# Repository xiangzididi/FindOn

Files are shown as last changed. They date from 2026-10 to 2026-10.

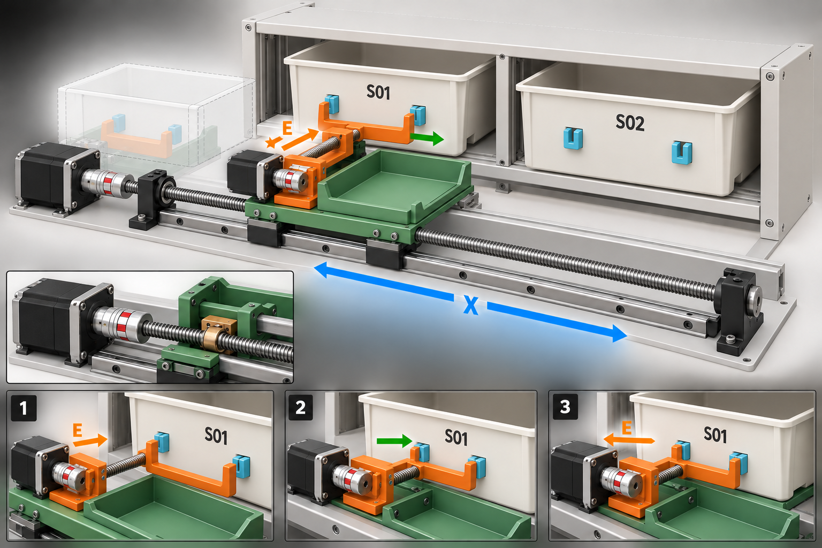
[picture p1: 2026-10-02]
docs/product-mechanism-concept-v1.png

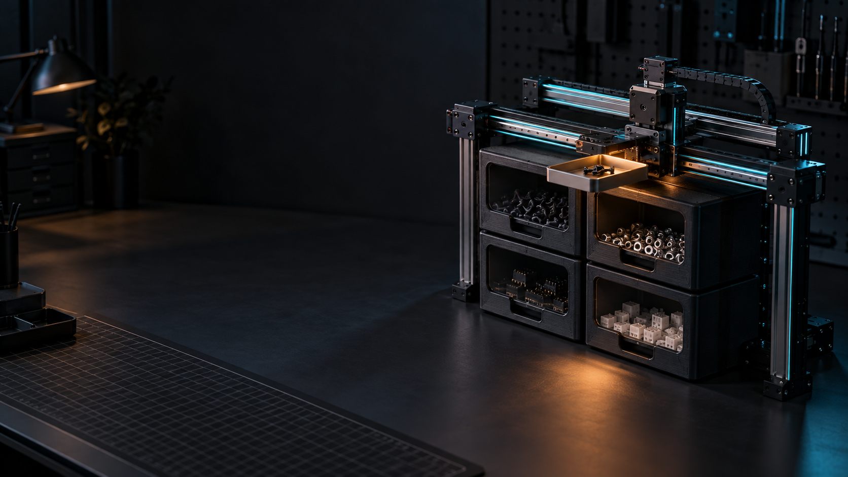
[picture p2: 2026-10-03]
public/assets/images/partgo-workbench-bg.jpg

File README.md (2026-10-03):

# PartGo · 桌面智能零件调度系统

PartGo 是桌面二维抽屉阵列式零件柜的 48 小时演示项目。电脑上的本地服务管理零件名称、盒位和任务历史，通过 USB 串口向 ESP32-S3 发送 `REFERENCE / FETCH / RETURN / STOP / RECOVER` 业务命令；ESP32-S3 控制 PD42S1 X 轴和 A4988 E 轴完成选格与抽盒。

当前演示配置启用同一层的 `S01/B01`、`S02/B02`，界面同时显示第二层 `S03/S04` 扩展位。加入 Y 轴并标定之前，第二层明确显示为不可用。

## 当前完成状态

- 新 PartGo 响应式前端已接入真实后端状态，支持搜索、浏览器语音、BOM 导入、格口编辑和批量顺序取料。
- Node.js 本地服务只监听 `127.0.0.1`，用 SQLite 保存盒位、任务、阶段事件和人工确认。
- USB 串口桥支持自动重连、控制器握手、JSONL 分片、任务超时和立即停止。
- ESP32-S3 最终固件已编译通过；上电不运动，未标定时报告 `CONFIG_LOCKED`。
- 取件送达和回件结束都要求操作员确认盒子实际位置。当前没有限位、编码器或盒体传感器，界面只显示真实存在的“开环脉冲计数”。
- 1×2 当前硬件与 2×2/Y 轴扩展共用一套格口协议和前端布局。

## 安全模拟演示

要求 Node.js 24 或更新版本。前端无需构建，也无需安装 npm 包。

```powershell
cd D:\Hackathon1st\Hackathon1st
node server.js
```

打开 <http://127.0.0.1:3210>：

1. 点击“确认机械原点”，勾选确认项。模拟模式只登记坐标，不驱动硬件。
2. 选择 `S01` 或 `S02`，确认运动区域清空后开始取件。
3. 等待页面进入“已到取物口”，取用零件并勾选取物口已清空。
4. 点击归还；模拟动作结束后目视确认提示，再点击“确认料盒已完整归位”。
5. 可导入 `.xlsx / .xls / .csv / .txt` 清单并按顺序处理已匹配的格口。

数据库保存在 `data/cabinet.sqlite`。不应同时启动多个服务进程打开同一数据库。

## USB 串口模式

Windows 下可直接双击项目根目录的 `启动管理系统.bat`。它只会关闭由本项目启动、身份核验一致且已确认空闲的旧进程；存在运动、待确认盒子、待恢复状态或无法读取旧服务状态时，会拒绝强制切换。如果 `COM9` 被其他程序占用，也会明确报错而不会结束未知进程。双击 `启动标定台.bat` 可切换到标定台；两个启动器默认使用 `COM9`，也可在命令行把其他串口作为第一个参数传入。

Python 只用于打开串口和解析 Excel：

```powershell
python -m pip install -r requirements.txt
.\start-hardware.ps1 -Port COM9
```

也可直接设置环境变量：

```powershell
$env:PARTGO_DEVICE_MODE = "hardware"
$env:PARTGO_SERIAL_PORT = "COM9"
$env:PARTGO_SERIAL_BAUD = "115200"
node server.js
```

服务会自动重连，但只有同时通过 `partgo-serial-v1` 握手、配置版本和标定指纹校验后才允许运动。旧轴测试固件、旧业务固件或参数不一致的固件只显示诊断状态，不会被当成可用控制器。任务进行时，主机每 500 ms 续租；控制器连续 2 s 收不到同一主机会话的心跳就停止输出并将任务判为失败。

## 固件

- `firmware/esp32s3_axis_test`：人工标定专用。保留受限点动/脉冲测试，不执行自动任务。
- `firmware/esp32s3_controller`：最终 USB 业务控制固件，同时兼容标定台的一次性受限人工移动。

编译最终固件：

```powershell
$pio = "$env:USERPROFILE\.platformio\penv\Scripts\platformio.exe"
& $pio run -d .\firmware\esp32s3_controller
```

最终固件的机械参数已经完整：X 比例为 `20000 pulse/mm`，E 根据带载实测“100 脉冲 = 19.6 mm”采用 `250/49 pulse/mm`（约 `5.1020 pulse/mm`）；48 mm 对接行程发送 245 个全步脉冲，相对 51 mm 实测可用行程保留约 3 mm 机械余量。`S01/S02` 的格口对位坐标分别为 `29.8 mm / 105 mm`，挂取动作再向右横移 `5.2 mm`。编译后的控制器不再处于 `CONFIG_LOCKED`，但每次上电仍必须把 X 放在最左侧取物处、E 完全回缩并由操作员确认原点后，才接受取回任务。完整协议见 [USB 串口协议 v1](docs/serial-protocol-v1.md)。

## 本地标定台

需要重新标定时，先烧录 `esp32s3_axis_test` 测试固件，把 X/E 滑块放在行程中间并打开电机电源。标定工具默认连接 `COM9`：

```powershell
.\start-calibration.ps1 -Port COM9
```

打开 <http://127.0.0.1:3212>。工具每次只发送一次 `ARM` 和一次有限运动，不提供连续转动；X 单次限制为 1–20 mm，E 在当前全步模式下单次限制为 1–100 脉冲。运动完成后填入卡尺实测距离，工具按当前实测比例换算标定基准。随后录入 E 对接行程、S01/S02 相对取物区的 X 坐标和方向，点击“写入最终固件配置”。

标定结果保存到 `config/motion-calibration.json`，同时生成 `firmware/esp32s3_controller/src/machine_calibration.h`。两者包含同一份安全参数指纹，上位机启动和控制器握手都会核对。缺少任何必需参数时不会写入，最终固件继续保持 `CONFIG_LOCKED`。无硬件时可验证界面：

```powershell
.\start-calibration.ps1 -Simulate
```

模拟模式会生成虚拟回执，不能作为实机标定结果，也不能写入或覆盖生产标定文件。

## 验证

```powershell
node --test
node --check server.js
node --check lib/cabinet.js
node --check lib/device.js
node --check lib/serial-transport.js
node --check public/app.js
node --check calibration/app.js
& "$env:USERPROFILE\.platformio\penv\Scripts\python.exe" -m unittest discover -s test -p "test_*.py"
```

固件验证：

```powershell
& "$env:USERPROFILE\.platformio\penv\Scripts\platformio.exe" run -d .\firmware\esp32s3_controller
```

自动化测试覆盖完整取回闭环、任务互斥与幂等、阶段顺序、人工盒位确认、故障/停止/超时、重启恢复、USB 握手、固件版本与标定指纹、任务心跳、受控恢复、串口分片与断线、HTTP 接口和数据库持久化。

## 目录

```text
server.js                         本机 HTTP 服务、静态资源与 BOM 接口
lib/cabinet.js                    SQLite、库存和任务状态机
lib/device.js                     模拟设备、JSONL 与 USB 设备适配器
lib/serial-transport.js           自动重连的 Python 串口桥进程
scripts/serial_bridge.py          pyserial 原始字节桥
scripts/parse_bom.py              本地 BOM 文件解析
scripts/calibration_server.py     有限运动、测量与固件参数生成
calibration/                      本地标定台网页
start-calibration.ps1             标定台启动入口
public/                           PartGo 前端，无构建步骤
firmware/esp32s3_axis_test/       标定测试固件
firmware/esp32s3_controller/      最终控制固件
docs/serial-protocol-v1.md        主机与 ESP32-S3 指令集合
config/cabinet.json               1×2 启用格与 2×2 扩展配置
config/motion-calibration.json    机械标定数据
test/cabinet.test.js              状态机、串口与 HTTP 测试
```

## 本机 API

`GET /api/state` 返回界面状态和临时请求令牌。所有写请求携带 `X-Cabinet-Token`；服务不对局域网或公网开放。

| 方法 | 路径 | 作用 |
| --- | --- | --- |
| `GET` | `/api/state` | 布局、设备、盒位和任务状态 |
| `PATCH` | `/api/boxes/{id}` | 更新零件名称和别名 |
| `POST` | `/api/tasks` | 提交取件或回件任务 |
| `POST` | `/api/tasks/{id}/confirm` | 人工确认盒子实际位置 |
| `POST` | `/api/device/reference` | 人工登记 X/E 原点 |
| `POST` | `/api/device/stop` | 软件停止并进入待恢复状态 |
| `POST` | `/api/device/recover` | 真实设备人工检查后恢复盒位记录 |
| `POST` | `/api/simulation/reset` | 仅模拟模式恢复初始状态 |
| `POST` | `/api/bom/import` | 本地解析 BOM 文件，最大 5 MB |

软件停止不能代替实体断电急停。当前设备没有实体急停和限位开关，调试时必须有人全程看护，并确保能立即切断 12 V 电机电源。ESP32 由 USB 独立供电，无法感知 12 V 是否断过；所以断线、停止、控制器复位、12 V 断电/重上电或动作不完整后，都必须先检查机械位置，再执行人工恢复和原点确认。

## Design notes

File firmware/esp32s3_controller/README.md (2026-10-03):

# ESP32-S3 最终控制固件

这是 PartGo 本地后端配套的 USB JSONL 控制器。它与 `esp32s3_axis_test` 分开保存：测试固件用于标定，控制固件只执行有限的业务任务。

当前机械配置已经完整：

- X 轴已测得 `20000 pulse/mm`；
- A4988 的 MS1/MS2/MS3 均接地，E 轴处于全步模式；带载实测100脉冲移动19.6mm，比例为 `250/49 pulse/mm`（约 `5.1020 pulse/mm`）；
- E 轴真实可用行程为 `51 mm`，对接命令取 `48 mm`，保留约 `3 mm` 机械余量；
- `S01`、`S02` 的格口对位坐标分别为 `29.8 mm`、`105 mm`，挂取时再向右横移 `5.2 mm`；
- 没有限位开关和 Y 轴。

本地标定台已经生成 `src/machine_calibration.h`。取件顺序为“到格口、E 伸出、X 右移挂钩、E 回缩、回取物区”，回件执行逆序释放动作。上电状态为 `UNREFERENCED`，不会自动运动；把 X 放在最左侧取物处、E 完全回缩并人工确认原点后才接受 `FETCH/RETURN`。

E轴由独立的 `e_axis.cpp/.h` 控制器管理，不再复用X轴运动结构。控制器单独维护A4988的STEP/DIR/EN时序、按比例换算得到的245脉冲对接行程、方向、超时和位置可信状态；伸出后保持使能，完成挂钩或脱钩横移后再执行负方向回缩并释放使能。

业务协议当前为配置版本 `6`。主机和控制器必须持有同一标定指纹；任务期间还必须维持同一主机会话的心跳租约，连续2秒失联会关断运动输出并报错。`RECOVER` 只清除逻辑状态，不产生电机脉冲，且要求操作员确认所有盒子都在柜内、运动区域已清空。当前没有实体急停，实机运行时必须有人能直接切断12V电机电源。

最终固件同时兼容本地标定台的受限人工控制：先发送 `ARM X/E CLEAR`，再执行一次 `TRAVEL X ±1–20 mm` 或 `PULSE E ±1–100`。授权 10 秒失效且只能使用一次；人工移动会清除原点状态，之后必须重新执行人工 `REFERENCE`。存在正在取还件的任务或有盒子停在取物区时，人工移动会被拒绝。

```powershell
$pio = "$env:USERPROFILE\.platformio\penv\Scripts\platformio.exe"
& $pio run -d .\firmware\esp32s3_controller
& $pio run -d .\firmware\esp32s3_controller -t upload --upload-port COM9
```

完整消息格式见 `docs/serial-protocol-v1.md`。

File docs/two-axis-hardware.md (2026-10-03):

# 单层两格：PD42S1 + A4988

接线图 R2：[PNG 预览](cabinet-wiring.png) / [SVG 矢量原图](cabinet-wiring.svg)。绘图源文件为 `scripts/draw-wiring.js`。图中 GPIO 是待实机复核的候选分配，12 V 是供电规划值。

## 已确认的硬件

- 主控：ESP32-S3-N16R8。
- X：PD42S1 PLC-TTL STEP/DIR，1.8° 电机、16 细分、1:50 减速箱、2 mm 导程丝杆/导轨，名义总行程 250 mm。
- E：三星光驱拆机微型步进电机、红色 A4988 StepStick 兼容板。2026-10-03 为提高带载启动能力，MS1/MS2/MS3 已由 3.3 V（1/16 细分）改接 GND（全步）；直接驱动标记为 T4 的丝杆，名义总行程约 50 mm，电机电源为 12 V。
- 当前 X/E 均没有微动开关，也没有盒子到位传感器。
- 导轨最左侧空位为固定取物区，一层两格为 S01、S02。

待标定参数记录在 `config/hardware.pending.json`。该文件不被业务服务或自动运动固件加载，`motion_enabled` 保持为 `false`。

## 机构与动作

X 滑块承载取货平台、E 丝杆模组和托盘；E 滑块连接双钩横梁。丝杆施力、托盘承重，移动线缆须覆盖全部 X 行程。柜格底面与托盘承接面应平齐，交界处不能卡住盒底。

取件顺序：

1. 人工确认 E 在完全回缩安全位置。
2. X 到目标格未嵌合坐标。
3. E 伸入到挂钩深度。
4. X 向右短移，使平台双钩与盒子双钩嵌合。
5. E 回缩，把盒子拉到托盘。
6. 人工确认盒子完全离柜且承托稳定。
7. X 左移到固定取物区。

回件按反序执行：X 到原柜格已嵌合坐标 → E 推回盒子 → X 向左短移脱钩 → E 空载回缩 → X 返回取物区。

每格需要未嵌合和已嵌合两个 X 坐标：`S01_ALIGN/S01_ENGAGED`、`S02_ALIGN/S02_ENGAGED`。若钩形相同，可使用公共 `HOOK_SHIFT = ENGAGED - ALIGN`。E 未回缩时，X 只允许执行已标定的短距离嵌合/脱钩，禁止跨格或去取物区。

结构概念图：[product-mechanism-concept-v1.png](product-mechanism-concept-v1.png)。它用于说明动作关系，不是加工尺寸图。

## 接线规划

N16R8 只说明存储配置，不能唯一确定第三方载板的外围占用。暂沿用已使用的 GPIO17/18 控制 X，GPIO15/16/7 控制 E；GPIO4/5 不连接。避开原生 USB GPIO19/20、存储接口与启动配置脚。八线存储配置下 GPIO35–37 不用于本项目。[Espressif 开发板说明](https://documentation.espressif.com/api/resource/path/docs/projects/esp-dev-kits/zh_CN/latest/esp32s3/esp32-s3-devkitc-1/user_guide_v1.0.html)

| ESP32-S3 / 电源 | 对端 | 说明 |
|---|---|---|
| GPIO17 | PD42S1 STP | 按已有共阳示例：空闲 HIGH、低脉冲有效；外接 10 kΩ 上拉到 3.3 V |
| GPIO18 | PD42S1 DIR | 方向待实测 |
| 3.3 V | PD42S1 COM | 信号公共端，不是电机电源 |
| 未连接 | PD42S1 EN | 不能靠软件撤销 X 使能 |
| GPIO15 | A4988 STEP | 空闲 LOW、高脉冲有效 |
| GPIO16 | A4988 DIR | 方向待实测 |
| GPIO7 | A4988 EN | 低有效，外部 10 kΩ 上拉使上电默认禁用 |
| 3.3 V / GND | A4988 VDD / GND | 逻辑供电 |
| 适配电机的电源 | A4988 VMOT / GND | 近端配置至少 47 µF 储能电容 |
| A4988 1A/1B、2A/2B | 电机两组线圈 | 断电用万用表确认线对 |
| 3.3 V | A4988 RESET、SLEEP | RESET/SLEEP 拉高 |
| GND | A4988 MS1、MS2、MS3 | 三只细分脚全部接地，使用全步模式 |
| GND | ESP32、PD42S1、A4988 逻辑地 | 共地，电机大电流回路单独布线 |

A4988 标准载板逻辑供电支持 3–5.5 V，电机供电支持 8–35 V。实物照片可见两只采样电阻均标记为 `R100`，按 0.10 Ω 计算：`Imax = Vref / (8 × 0.10) = Vref / 0.8`。电机额定电流未知，首次空载测试采用 `Vref≈0.20 V`，对应约 0.25 A 限流；该数值只作为低电流起点。禁止带电插拔电机。[Pololu 载板说明](https://www.pololu.com/product/1182)

## 步进比例

- X 按已声明参数推算为 `200 × 16 × 50 ÷ 2 = 80000 pulse/mm`，但 2026-10-03 实测正反向均为 `400000 pulse / 20 mm = 20000 pulse/mm`，往返观察误差为 0 mm。当前固件采用实测值；细分、减速比或丝杆实际导程至少有一项与声明值不一致，后续需逐项核查。
- E 轴最新实测为100脉冲移动19.6mm，即 `250/49 pulse/mm`（约 `5.1020 pulse/mm`），因此48mm对接行程四舍五入为245个全步脉冲。最终固件直接采用该实测比例，不再根据细分倍率推算。

X 当前采用实测值 20000 pulse/mm，并应继续用百分表或卡尺复核。E 使用固件的 `PULSE E` 原始脉冲模式，但须先完成全步空载诊断。减速箱回程间隙会使 X 的正反向定位出现差异，格位标定应统一从同一方向逼近；若越过目标，先退回足够距离再重新逼近。

## 无开关时的参考方式

由于没有原点/限位开关，当前不能自动回零。测试前先切断电机电源，把 X 人工对准左侧取物区物理标记，把 E 对准完全回缩安全标记；上电后由操作者确认参考点。以下任一情况都使参考失效：控制器复位、电机掉电、堵转、丢步、人工移动、传动打滑。

软限位只能在人工参考有效并完成实测标定后使用。软件无法检测机械撞端，因此当前测试固件只允许 X 每次解锁后 0.1–1.0 mm 低速点动，以及 E 每次解锁后最多 320 个原始脉冲；不提供自动取放、连续旋转或 HOME。

## 50 mm 行程校核

STL 没有单位，以下假定坐标单位为 mm。原文件未修改，分析结果和四视图在 `models-analysis.json`、`models-preview.svg`。

| 模型 | X × Y × Z 包围盒 |
|---|---|
| 架子 | 157 × 49.90 × 62.90 |
| 盒子及钩件 | 70 × 51.40 × 53 |

若沿模型 -Y 抽出，盒子后边界 Y=-5，柜体前边界 Y=-49.90，跨越约需 44.90 mm。增加 2 mm 净空后约 46.90 mm，50 mm 名义行程只剩约 3.10 mm。还未计入装配误差、挂钩行程和制动余量，必须测量实际有效行程。

## 实机开发顺序

1. 核对 PD42S1 为 16 细分；确认 A4988 的 MS1/MS2/MS3 均接 GND、Vref 约 0.19–0.20 V；检查电源、共地、STEP 空闲电平。
2. 切断电机电源，人工把两轴放到安全中间位置。烧录无开关点动固件，上电确认不会自动运动。
3. E 先以全步模式完成空载诊断，确认能稳定旋转后再从行程中部标定。X 已实测为 20000 pulse/mm、正方向向右；继续以 0.5–20 mm 分级复核实际位移。
4. 制作 X 取物区和 E 完全回缩的耐久物理标记，确定人工参考流程。
5. 标定 `x_pickup`、`x_S01_align`、`x_hook_shift`、`e_dock`、`e_extracted`，先完成 S01 分步动作。
6. 空盒完成一次 FETCH1/RETURN1，逐步加入运动超时、软限位和 E/X 互锁，再增加 S02。
7. 真实位置每个关键步骤先由人工确认。没有传感器时，脉冲发完只代表命令完成，不能证明盒子已离柜、到位或未卡住。

当前网页只模拟两格流程，尚未连接 COM 口。自动状态机必须能够中断当前脉冲并取消后续动作，停止请求不能排在运动队列尾部。

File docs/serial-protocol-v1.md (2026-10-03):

# PartGo USB 串口协议 v1

本协议用于本机 Node.js 服务与 ESP32-S3 控制器之间的 USB CDC 通信。浏览器只访问本机 HTTP API，不直接打开串口，也不向控制器发送脉冲数、速度或方向。

## 传输格式

- 串口：`115200 8N1`，UTF-8。
- 每条消息是一个 JSON 对象，以 `\n` 结束（JSON Lines）。
- 单行最长 768 字节；超长、无效 JSON、未知字段值均拒绝。
- 协议号字段为 `"v":1`，协议名称为 `partgo-serial-v1`。
- `task_id`、`request_id` 仅允许字母、数字、下划线和连字符，最长 64 字符。
- 任意时刻收到单字节 `!`，控制器立即停止 STEP 输出并关闭可控的电机使能。它是 JSON 解析之外的紧急软件停止通道。

## 状态

| 状态 | 含义 | 允许的操作 |
| --- | --- | --- |
| `CONFIG_LOCKED` | 缺少 E 轴比例或格口坐标 | `hello`、`status`、`stop` |
| `UNREFERENCED` | 配置完整，但本次上电尚未人工确认原点 | `hello`、`status`、`REFERENCE`、`stop` |
| `READY` | 原点有效，空闲 | 业务命令、查询、停止 |
| `PRESENTED` | 一个料盒位于左侧取物口 | 只允许对应格口的 `RETURN`、查询、停止 |
| `BUSY` | 正在执行任务 | 查询、停止 |
| `RECOVERY_REQUIRED` | 停止、超时、通信异常或动作未完整结束 | 查询、停止、人工确认后的 `RECOVER` |

控制器上电绝不自动运动。当前机构没有限位开关，因此 `REFERENCE` 不是自动回零：操作员必须先断开运动、把 X 平台放到左侧取物原点、把 E 轴置于完全收回位置、把所有料盒放回对应柜格并清空运动区域，再在页面中确认。ESP32 由 USB 独立供电，无法检测 12 V 电机电源中断；12 V 只要断过或重新上电，现有原点就必须视为无效，人工恢复并重新执行 `REFERENCE`。

## 主机发往 ESP32-S3

### 握手

```json
{"v":1,"type":"hello","request_id":"boot-01","host_session_id":"host-01"}
```

控制器返回同一 `request_id` 的 `hello`。本机只有在节点、协议号和固件信息均有效后才显示“控制器已验证”。

### 查询状态

```json
{"v":1,"type":"status","request_id":"status-01","host_session_id":"host-01"}
```

### 人工建立原点

```json
{"v":1,"type":"command","task_id":"task-ref-01","cmd":"REFERENCE","config_version":6,"calibration_id":"sha256:cc1c95986974daccbf755497cff7d538567dadf5f3a38973d9f94a4cfc739ef8","host_session_id":"host-01","manual_reference_confirmed":true,"area_clear":true}
```

控制器不执行电机动作，只把当前位置登记为 `X=0 mm`、`E=0 mm`。缺少两个确认字段时必须拒绝。

### 取件

```json
{"v":1,"type":"command","task_id":"task-fetch-01","cmd":"FETCH","slot_id":"S01","config_version":6,"calibration_id":"sha256:cc1c95986974daccbf755497cff7d538567dadf5f3a38973d9f94a4cfc739ef8","host_session_id":"host-01","area_clear":true}
```

### 回件

```json
{"v":1,"type":"command","task_id":"task-return-01","cmd":"RETURN","slot_id":"S01","config_version":6,"calibration_id":"sha256:cc1c95986974daccbf755497cff7d538567dadf5f3a38973d9f94a4cfc739ef8","host_session_id":"host-01","area_clear":true}
```

### 人工恢复

```json
{"v":1,"type":"command","task_id":"task-recover-01","cmd":"RECOVER","config_version":6,"calibration_id":"sha256:cc1c95986974daccbf755497cff7d538567dadf5f3a38973d9f94a4cfc739ef8","host_session_id":"host-01","confirmed_all_stored":true,"area_clear":true}
```

`RECOVER` 不产生运动，只关闭输出、清除板内取物口关联和坐标，并进入 `UNREFERENCED`。后台只有收到成功结果后才把 SQLite 盒位恢复为 `STORED`；随后仍需单独执行 `REFERENCE`。

### 停止

```json
{"v":1,"type":"stop","task_id":"task-fetch-01"}
```

本机服务同时发送单字节 `!`，不等待一整行 JSON 被解析。网页停止按钮只是软件停止请求；当前实物没有实体急停，操作者必须始终能直接切断 12V 电机电源。

## ESP32-S3 发往主机

### 握手与状态

```json
{"v":1,"type":"hello","request_id":"boot-01","protocol":"partgo-serial-v1","node":"ESP32-S3","firmware":"PARTGO-CONTROLLER-2.1.0","state":"UNREFERENCED","motion_configured":true,"referenced":false,"busy":false,"config_version":6,"calibration_id":"sha256:cc1c95986974daccbf755497cff7d538567dadf5f3a38973d9f94a4cfc739ef8","presented_slot_id":null,"layout":{"rows":2,"columns":2,"has_y_axis":false},"calibration":{"x_pulse_per_mm":20000,"e_pulse_per_mm":5.1020,"e_scale_numerator":250,"e_scale_denominator":49,"e_driver_microsteps":1,"e_dock_um":48000,"x_hook_shift_um":5200},"slots":[{"id":"S01","enabled":true,"calibrated":true},{"id":"S02","enabled":true,"calibrated":true},{"id":"S03","enabled":false,"calibrated":false},{"id":"S04","enabled":false,"calibrated":false}]}
```

`status` 响应字段相同，只把 `type` 改为 `status`。`motion_configured=false` 时，本机页面显示“待标定”，并禁用自动取还件。

## 标定台人工控制兼容层

最终固件也接受标定台使用的受限纯文本命令：`STATUS`、`ARM X CLEAR`、`ARM E CLEAR`、`TRAVEL X ±1–20`、`PULSE E ±1–100`、`STOP` 和单字节 `!`。E 轴原始值表示全步，实测100脉冲移动19.6mm，即 `250/49 pulse/mm`。每次 `ARM` 在10秒内只允许一次移动。人工移动会清除绝对原点并返回 `position=UNREFERENCED`；必须重新确认X位于取物区、E完全回缩并执行 `REFERENCE`，才能恢复自动任务。正在执行任务或取物区存在盒子时拒绝人工移动。

### 接受或拒绝

```json
{"v":1,"type":"ack","task_id":"task-fetch-01","accepted":true}
```

```json
{"v":1,"type":"ack","task_id":"task-fetch-01","accepted":false,"error":"CONFIG_LOCKED"}
```

常见错误码：`INVALID_MESSAGE`、`PROTOCOL_VERSION`、`CONFIG_VERSION`、`CALIBRATION_ID`、`CONFIG_LOCKED`、`REFERENCE_REQUIRED`、`E_CLEAR_REQUIRED`、`E_POSITION_UNKNOWN`、`E_AXIS_START_FAILED`、`E_MOTION_TIMEOUT`、`HOST_HEARTBEAT_TIMEOUT`、`BUSY`、`UNKNOWN_SLOT`、`SLOT_DISABLED`、`Y_AXIS_REQUIRED`、`AREA_NOT_CLEAR`、`MANUAL_REFERENCE_REQUIRED`、`MANUAL_RECOVERY_CONFIRMATION_REQUIRED`、`DUPLICATE_TASK_ID`。

### 阶段事件

```json
{"v":1,"type":"event","task_id":"task-fetch-01","seq":3,"phase":"SLOT_REACHED","sensors":{"slot_id":"S01","motion_complete":true,"x_target_um":29800,"evidence":"open_loop_pulse_count"}}
```

当前硬件没有限位开关、编码器和盒体传感器，因此 `sensors` 字段描述的是开环脉冲计数结果，不能伪装成真实传感器。后端只在完整收到所有阶段后进入“待人工确认”；盒子位置由操作员确认后才写入库存状态。

阶段顺序：

- `REFERENCE`：`REFERENCE_ACCEPTED` → `HOME_CONFIRMED`
- `FETCH`：`E_CLEAR` → `MOVING_TO_SLOT` → `SLOT_REACHED` → `DOCKING` → `DOCK_REACHED` → `HOOK_SHIFTING` → `HOOK_ENGAGED` → `PULLING` → `EXTRACTION_REACHED` → `TRANSFER_READY` → `MOVING_TO_PICKUP` → `PICKUP_REACHED`
- `RETURN`：`TRANSFER_READY` → `MOVING_TO_SLOT` → `SLOT_REACHED` → `PUSHING` → `INSERTION_REACHED` → `UNHOOKING` → `HOOK_RELEASED` → `RETRACTING` → `E_CLEAR` → `MOVING_TO_PICKUP` → `PICKUP_REACHED`

机械动作固定为：取件时到达格口基准坐标，E 伸出 `48 mm`，X 向右 `5.2 mm` 挂住盒子，E 回缩 `48 mm`，再回到左侧取物区。回件执行逆序动作：到达格口右偏 `5.2 mm` 的坐标，E 伸出 `48 mm`，X 向左 `5.2 mm` 释放盒子，E 回缩后返回取物区。

### 最终结果

```json
{"v":1,"type":"result","task_id":"task-fetch-01","success":true,"state":"PRESENTED"}
```

```json
{"v":1,"type":"result","task_id":"task-fetch-01","success":false,"state":"RECOVERY_REQUIRED","error":"MOTION_TIMEOUT"}
```

## 1×2 与 2×2 扩展

固件始终使用 `slot_id` 查表，不接收行列坐标。当前配置启用 `S01`、`S02`，两格都位于同一行；`S03`、`S04` 为第二行预留。加入 Y 轴并完成标定前，第二行格口返回 `Y_AXIS_REQUIRED`。本机后端可以在同一页面显示这些扩展格，但会明确标成不可用。

## 断线和幂等规则

- 本机数据库用 `request_id` 防止网页重复提交。
- 控制器同一时刻只接受一个 `task_id`；重复或冲突 ID 被拒绝。
- 运动命令同时校验结构版本和完整标定指纹；任一不一致都在产生脉冲前拒绝。
- 任务期间主机每 500 ms 查询状态，固件只接受同一 `host_session_id` 续租；2秒没有有效心跳即停止并进入恢复状态。主机1.5秒收不到任何回程状态也会停止续租并发送 `!`。
- 执行中串口断开、服务超时或 ESP32 重启时，后端把盒位标为未知并进入恢复状态，不自动重放任务。
- 任务成功只说明预定脉冲序列完整结束。是否真正抓住、抽出或归位零件盒，仍由操作员确认。

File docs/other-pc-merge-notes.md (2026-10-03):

# 另一台电脑项目合并记录

来源：项目根目录 `Hackathon1st.zip` 与 `docs/对话记录新.txt`。

## 已采用

- 移动平台上的 E 轴采用双钩横梁，盒子具有对应双钩。
- 挂钩靠 E 轴伸入后 X 轴向右短移完成；脱钩靠回柜后 X 轴向左短移完成，不增加舵机。
- 左侧固定取物区、S01、S02 的机械布局。
- 产品结构概念图 `product-mechanism-concept-v1.png`。
- 开发顺序以实机最小闭环为先：安全点动 → 方向/比例 → 单格分步动作 → FETCH1/RETURN1 → 第二格 → 上位机。

## 最新实物确认与取舍

用户已确认 X 带 1:50 减速箱，X/E 均没有微动开关；这两项已合并到硬件配置、接线图和点动固件。

后续实机信息已修正：X 按 1.8°、16 细分、1:50 和 2 mm 导程理论计算为 80000 pulse/mm，但实测为 20000 pulse/mm，当前固件使用实测值并保留参数差异待核查。E 使用三星光驱拆机微型步进电机和 T4 丝杆，步距角、导程及 pulse/mm 未知，必须先完成全步空载诊断再标定。

压缩包固件允许无端点保护的连续高速 `SPIN X`，最高 160000 pulse/s，且没有软件时长上限；当前不采用。新的 `GEWU-AXIS-TEST-2.0-NO-ENDSTOPS` 仅允许每次解锁后的 0.1–1.0 mm 点动。

## 单盒 MVP 所需标定量

- `x_pickup`
- `x_S01_align`
- `x_hook_shift`
- `e_dock`
- X/E 正方向电平
- X/E 实测 pulse/mm

S01 分步通过后，再增加 `x_S02_align`。自动动作仍需保留停止、软限位、E/X 横移互锁，以及拉盒完成后的人工确认。

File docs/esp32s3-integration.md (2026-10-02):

> 硬件更新：主控为 ESP32-S3-N16R8，X 为丝杆/导轨。用户示例采用 PD42S1 STP/DIR 脉冲控制；不再默认使用 PD42S1 UART。USB JSONL 是 PC 与 ESP32 的通信，与电机脉冲接口不同。详见 two-axis-hardware.md。

# 两轴协议 v3 更新

当前硬件与行程校核以 [two-axis-hardware.md](two-axis-hardware.md) 为准：PD42S1 TTL STEP/DIR 经 1:50 减速箱驱动 X，A4988 驱动 E，仅启用 S01/S02。两轴均无原点/限位开关；板端协议文件依旧只做模拟，独立点动固件用于实机低速标定。

# ESP32-S3 联调与下一阶段实现

主控为 ESP32-S3-N16R8；驱动、候选引脚和名义行程已记录。当前没有限位输入，实际方向、可用行程和各坐标尚未标定。

## 当前代码边界

- `lib/device.js`：PC 内存模拟器，以及接收 Node.js 双工流的 JSONL 设备适配器。适配器已用假流验证分片、ACK、结果、断连、停止和超时。
- `firmware/esp32s3_protocol_demo/esp32s3_protocol_demo.ino`：ESP32-S3 串口协议演练程序，所有传感器值均由模拟阶段生成。没有 GPIO 操作，不会输出电机脉冲。
- Web 服务当前仅使用 PC 模拟器。尚未接入 COM 口，也没有把板端演练程序接成网页设备。
- 板端源码尚未编译/刷板验证。本机未检测到 Arduino CLI 或 PlatformIO；不能把源码存在视为固件验证通过。

## 刷板联调步骤

1. 在 Arduino IDE 中安装 Espressif 的 ESP32 板卡包及 ArduinoJson 7，选择板子的准确型号及 Flash/PSRAM 配置。
2. 打开同名目录里的 `.ino`。使用原生 USB 接口时，按实际开发板选择 USB CDC；若插的是 CP210x/CH340 转串口口，应使用对应 UART 配置，二者不能混淆。
3. ESP32-S3 原生 USB CDC 的官方示例设置为 `USB CDC On Boot: Enabled`、`Upload Mode: UART0 / Hardware CDC`。具体菜单随板卡与核心版本不同，以实际板卡配置为准。
4. 上传后，串口监视器选择 115200 和换行符。依次发送下面的 JSON，每次等待上一条 `result`。

```json
{"type":"status"}
{"type":"command","task_id":"bench-home-1","cmd":"HOME","slot_id":null,"config_version":3}
{"type":"command","task_id":"bench-fetch-1","cmd":"FETCH","slot_id":"S02","area_clear":true,"config_version":3}
{"type":"command","task_id":"bench-return-1","cmd":"RETURN","slot_id":"S02","area_clear":true,"config_version":3}
```

所有返回都带 `"mode":"protocol_simulation"`。这只能证明通信和流程演练，不能证明真实取放。

运行中停止：

```json
{"type":"stop","task_id":"bench-fetch-1"}
```

停止后先查询状态；仅在此无电机的演练固件里，可以发送以下命令重置模拟位置，再用新 task_id 回零。

```json
{"type":"reset_simulation","confirmed":true}
```

## 通信契约 v3

USB 串口，115200、8N1（原生 USB CDC 的实际传输不依赖传统 UART 位速率），UTF-8，每条 JSON 以 `\n` 结束。发送方逐任务执行，不在 PC 上堆积运动队列。

| 类型 | 必需字段 | 含义 |
|---|---|---|
| command | task_id, cmd, slot_id, config_version | 动作请求，cmd 为 HOME/FETCH/RETURN |
| ack | task_id, accepted, error（拒绝时） | 接收/拒绝，不表示完成 |
| event | task_id, seq, phase, sensors | 单调递增阶段事件；seq 从 1 开始 |
| result | task_id, success, error（失败时） | 任务结果，成功前必须收到完整阶段及传感器确认 |
| status | state, task_id, presented_slot | 重新连接后的状态核对 |
| stop | task_id | 停止请求；不替代实体急停 |

回零：HOMING → E_CLEAR → X_HOMING → HOME_CONFIRMED。

取件：E_CLEAR → MOVING_TO_SLOT → SLOT_REACHED → PULLING → EXTRACTION_REACHED → TRANSFER_READY → MOVING_TO_PICKUP → PICKUP_REACHED。

回件：TRANSFER_READY → MOVING_TO_SLOT → SLOT_REACHED → PUSHING → INSERTION_REACHED。

E_CLEAR 要求 e_clear=true；SLOT_REACHED 要求 x_in_position=true 且 slot_id 等于目标格；HOME_CONFIRMED 要求 homed=true、home_reference_valid=true；E 端点事件要求 axis_in_position=true 和 axis_endpoint=OUT/IN。这些都是模拟值。A4988 没有真实位置反馈，实际驱动不得将发完脉冲等同传感器到位。

板端 result 仅结束运动流程；服务端取回件进入 AWAITING_CONFIRMATION，通过 POST /api/tasks/{id}/confirm、confirmed=true 完成人工盒子确认。直接串口演练不包含该管理端步骤。

PC 对异常阶段、序号、缺少传感器回执均拒绝认定完成。真实固件应独立完成互锁，不能依赖 PC 的事后校验避免碰撞。

板端演练仅缓存最近 16 个 task_id 并拒绝重复，缓存重启即失效。正式固件必须补充持久化任务身份、上电位置核对和断线恢复。PC 不应自动重发未决动作，先发 status 查询；已经完成的任务应取回缓存结果，不能重新运动。

## 接真实硬件前待补齐

请记录以下信息，之后才能选择驱动方式、分配 GPIO、写脉冲和回零逻辑：

| 信息 | 示例（不是当前选型） |
|---|---|
| ESP32-S3 板子完整型号 | 模组 Flash/PSRAM、开发板照片/丝印、USB 口用途 |
| X/Z/E 电机与驱动型号 | STEP/DIR 驱动或其他控制方式、额定电流、使能电平 |
| 拉钩机构 | 舵机型号、电压、开合角度、推回脱钩方式 |
| 传动参数 | 同步带齿距/齿数、丝杆每圈导程、细分设置 |
| 传感器 | 当前无传感器；后续若增加，记录类型、电压、电平和机械触发位置 |
| 行程与重量 | X/Z/E 有效行程、盒子尺寸、移动总成重量 |
| 安全回路 | 实体急停、垂直轴失电防坠、逻辑电源与电机电源 |

实现顺序：单轴低速点动 → 人工基准和软限位标定 → 单格分步对接 → 人工确认取出与回柜 → 两格标定 → 串口实际闭环。

真实运动阶段必须由“运动完成＋传感器条件”推进，不能沿用演练程序里的 650 ms 定时推进。标定配置须包含版本、各格坐标、速度、加速度、软限位和取物口位置。启用 COM 口前还要添加连接握手、设备模式核验、启动状态核对；网页应明确显示真实设备或板端模拟，不能静默切换模式。

参考：[Espressif USB CDC 官方说明](https://docs.espressif.com/projects/arduino-esp32/en/latest/tutorials/cdc_dfu_flash.html)、[ArduinoJson 7 JsonDocument](https://arduinojson.org/v7/api/jsondocument/)。

协议 v3：TRANSFER_READY 必须带 box_clear_of_rack=true、box_supported=true；PICKUP_REACHED 必须带 x_in_position=true、location=PICKUP。目前只模拟，不代表真实传感器验证。

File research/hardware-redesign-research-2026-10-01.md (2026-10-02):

# 硬件吐槽与功能诉求：48h redesign 选题调研

检索日期：2026-10-01。面向擅长嵌入式开发与物联网、可使用常见传感器和加工设备的团队。

## 调研口径

- 覆盖智能家居、普通家电、充电供电、耳机与外设。资料来自消费调查、V2EX、Reddit、Home Assistant 社区及厂商文档。
- 下表保存了 31 个去重的社区主题作为需求证据。同一主题的不同评论不算独立主题；这些主题是按问题定向检索得到的案例集，不是随机样本。
- **不能用这 31 个主题的分类数量推算全网提及率或市场占比。** 搜索结果数量、浏览量、投票数、回复数也不等于赞同某诉求的人数。
- “哪些最多”优先依据同一调查内的比例；不同国家、年份、问法的调查不合并排序。社区案例用于说明具体情境与长期重复出现的诉求。
- 历史帖子说明当时的使用体验，不能证明相关型号在 2026 年仍有同一问题。没有对当前所有产品做竞品穷举，也不声称方案全球首创。
- 部分主题核对了网页正文，其余仅使用公开检索摘录；在证据表中标明。没有抓取私密社区、登录后内容或完整评论数据库。

## 一、能量化比较的需求

### 国内智能家居家电调查

江苏省消保委于 2025-12-25 发布调查，媒体披露有效线上问卷 7,621 份；另结合 2025-01-01 至 2025-11-30 的省内相关消费维权舆情。问卷和舆情是两类材料，不能混成一个样本。

以下是已核验的三项使用难点，按披露比例排列：

| 难点 | 披露比例 | 可以转成什么功能需求 |
|---|---:|---|
| 功能冗余、华而不实、功能闲置 | 44.29% | 常用功能直接可达；自动化真正减少操作与维护 |
| 操作复杂、学习成本高 | 37.96% | 实体控制、明确反馈、免反复打开 App |
| 生态割裂、跨品牌兼容困难 | 37.12% | 统一控制入口、有限但可靠的跨设备联动 |

来源：[样本与方法：扬子晚报/紫牛新闻](https://www.yangtse.com/news/ch/202512/t20251225_304240.html)、[功能冗余与操作复杂：中国新闻周刊](https://news.inewsweek.cn/yysbg/2026-03-17/29347.shtml)、[跨品牌兼容：家电网经新浪转载](https://finance.sina.com.cn/tech/roll/2025-12-30/doc-inhepszw4375331.shtml)。

核验限制：江苏省消保委官网在本次访问时显示 2026-10-01 的系统维护公告，未取得原始问卷及完整交叉表。上述数字保留媒体披露口径；不能宣称是全国随机样本，也不能把它们说成全部硬件的前三名。37.96% 的直接来源是中国新闻周刊的报道。网上部分文章把“58.62% 遇到过问题”改写成“58.62% 掉线率”，本报告不采用这种改写。

### 美国智能家居调查中的故障体验

American Home Shield 在 2024-12 调查 1,006 名美国房主和租客，并于 2025-05 发布结果。该商业机构调查报告对智能设备用户披露以下比例：

| 故障体验 | 比例 |
|---|---:|
| Wi-Fi/互联网连接问题 | 46% |
| 停电导致系统受影响 | 33% |
| 电池耗尽导致设备失效 | 20% |
| 卡屏、无法启动等故障 | 20% |
| 安装、配对困难 | 19% |
| App 崩溃、更新失败等软件问题 | 15% |

这支持将连接可靠性列为优先验证项。该调查还披露 57% 的受访者担心隐私；这属于“担忧”，不能当成实际泄露率。

来源：[AHS 调查原文及方法](https://www.ahs.com/home-matters/quick-tips/smart-home-survey/)。上述比例只在该调查内部比较，不能直接与中国调查混排。

补充：[Deloitte 2023 智能家居调查](https://www.deloitte.com/us/en/insights/industry/telecommunications/connectivity-mobile-trends-survey/2023/smart-home-industry-adoption-trend.html)中，79% 的智能家居用户认为互操作性非常或比较重要，34% 希望所有设备无缝协作。这是重要性评价，并非投诉率。

## 二、从具体吐槽到改进方向

以下“用户表达”为对材料的归纳转述，不是逐字引语。优先级是基于团队能力、原型范围与演示效果的判断，不是流行度排名。

| 诉求 | 典型情境 | 可以迭代的产品与功能 | 48h 优先级 |
|---|---|---|---|
| 断网仍能完成基本操作 | 半夜关空调，语音服务报告网络错误 | 遥控器/控制面板：本地执行、实体入口、保存设置 | 高 |
| 跨品牌统一、少装 App | 控制不同设备需要切换多个入口 | 有限设备集的统一遥控器；显示实际执行状态 | 高 |
| 常用功能保留实体操作 | 湿手、戴手套、视力不便时难用触摸面板 | 大按键、旋钮、可触摸区分；常用操作一键直达 | 高 |
| 插拔一个设备不影响其他设备 | 多口充电器重新分配功率，其他负载重启 | 供电座增加带缓冲的关键接口、功率预留与电压监测 | 高，须有电源经验 |
| 切换音源可控、不被抢声音 | 电脑开会，手机声音抢占耳机 | 实体音源选择、当前音源显示、会议锁定 | 中 |
| 指示灯和普通提示音可控 | 卧室指示灯刺眼；家电反复蜂鸣 | 指示灯状态转移至无背光显示；普通提示可改振动 | 高，首版只处理指示灯 |
| 电池可换、低电量可预知 | 小电池耗尽，传感器失效；耳机电池老化 | 可更换供电模块、USB/电池双供电、离线故障区分 | 中 |
| 自动化尊重手动操作 | 人坐着没动，灯被关；手动设置被规则覆盖 | 手动优先、明确自动/手动模式、在场检测与退出条件 | 高 |
| 完成状态能保留、提醒有确认 | 洗完没注意，或取衣后继续收到提示 | 家电状态贴：运行/疑似完成/待处理/已确认的状态机 | 高 |

## 三、八个具体功能方案

### A. 有回执的实体遥控器

**改造对象：**普通红外遥控器、家庭控制面板。对应证据 01—07。

**用户流程：**选择台灯或风扇，按实体按键；屏幕先显示“已发送”，传感器确认变化后显示“已生效”，超时显示“未确认”。网络外线中断时，已配置的本地操作继续可用。

**改进点：**让命令发送与真实设备状态区分开；手动使用原遥控器后，也能从传感器重新获取状态。

**48h 范围：**一个手持控制器、两件明确型号的现有设备。ESP32、编码器/大按键、红外发射模块、独立光敏或振动反馈节点。灯用光线变化验证，风扇用经校准的振动反馈。先验证摆放条件，避免把环境变化当作设备响应。

**验证：**遮挡红外时不得显示成功；换原遥控器操作后状态能更新；断开外网后重复 20 次操作，记录成功率和延迟。

**边界：**红外通常没有回执，传感器只能提供有限条件下的观测。对只有开关切换码的设备，不自动重复发送，以免重复切换。Home Assistant 已支持可兼容设备的本地控制，本项目要改进的是交互与反馈闭环。[已有能力参考](https://www.home-assistant.io/faq/is-my-data-private/)

### B. 带“保活口”的桌面供电座

**改造对象：**多口 USB 充电器/桌面供电座。对应证据 08—13。

**用户流程：**把不能被中断的设备接到标有“保活”的接口；其他口按剩余预算供电。插拔其他负载时，关键接口依靠独立电源路径和缓冲继续工作；显示当前电压与缓冲状态。

**48h 范围：**只做已确定负载范围的 5V 系统，使用现成、匹配负载的电源路径管理/UPS 模块，配电压电流检测和 ESP32。一个运行计时的开发板做关键负载，一个风扇或灯做可插拔负载。缓冲容量与切换能力应按实测电流和跌落时间选择。

**验证：**记录关键负载运行时间和最低供电电压；连续插拔 30 次及短时输入中断测试，统计复位次数。结果未实测前不承诺“零中断”。

**边界：**这是低压供电原型，不等同于完成 100W USB-PD 快充产品。已有供电产品也能实现类似目标，改进可以聚焦显式优先级、关键口状态与异常解释。Anker 对特定型号的 FAQ 确认，端口数量变化时重新分配功率可能带来短时充电中断；不能据此说所有充电器都会断电。[厂商文档](https://service.anker.com/article-description/Anker-Charger-100W-3-Ports-Smart-Display-FAQ)

### C. 暗夜状态贴：把指示灯的信息搬家

**改造对象：**路由器、充电座、音箱等设备的状态指示灯。对应证据 19—23。

**用户流程：**给普通状态 LED 装一个可拆的遮光小帽；内部光敏/颜色传感器读取亮灭或闪烁，多个节点把状态传到床头无背光电子纸。按一下即可查看哪台设备在运行、断连或出现预设闪灯状态。

**改进点：**同时保留黑暗环境与状态可见性。用户无需逐个打开 App，也无需为查看状态反复揭胶带。

**48h 范围：**两种明确设备、两枚光学采集贴、一个电子纸接收端。每个设备手动校准，只识别关/亮/闪三种模式，再由用户指定标签。

**验证：**外部环境光变化下的识别稳定性、开关灯/重启后的恢复、夜间遮光效果、节点断连时能否显示“状态未知”。

**边界：**不能从任意 LED 自动理解全部故障码；首版只处理普通状态指示灯，不覆盖设备的重要安全告警，也不声称消除了蜂鸣声。亮灯与状态含义必须按该型号确认。

### D. 家电“待处理”状态贴

**改造对象：**旧洗衣机、烘干机及相应完成提示。对应证据 29—31。

**用户流程：**贴上振动传感节点和门磁，记录一次指定程序。结束后，接收端持续显示“疑似完成，待取衣”；开门后记录“已开门，待确认”，确认取出才复位。也可明确约定开门即确认，但不得声称传感器看见了衣服被取走。

**改进点：**完成提示具有持续状态与确认机制；多个家庭成员共享进度，减少重复提醒。

**48h 范围：**只适配一台机器的一两个程序。ESP32、加速度计、门磁、一个实体确认按钮及小屏。振动静止不能单独认定完成，需要持续时间、先前运行历史等条件，并保留“未确认”。

**验证：**覆盖运行中暂停、正常结束、开门未取衣、紧接着再洗一轮。压缩模拟流程必须与真实运行测试分开说明。

**边界：**完成通知和门磁确认已有 Home Assistant 方案。机会在免拆改安装、少量校准、可理解状态和误报控制，而不是“第一次让洗衣机发通知”。

### E. 有“会议锁”的音频切换座

**改造对象：**耳机音源切换、桌面音频切换器。对应证据 14—18。

**功能：**实体选择手机/电脑音源；灯明确显示当前路由；会议锁期间忽略自动切换请求，手机提示不抢走电脑声音。呼叫提醒与声音路由分开呈现。

**48h 范围：**两路有线模拟音频输入、一路耳机输出、现成音频切换模块、控制器与实体按键。先验证手动路由和锁定；蓝牙输入只有在现成模块接口明确时加入。麦克风通道需另行设计，首版不能暗示完整双向通话已支持。

**验证：**两源同时播放时的路由、切换爆音、锁定行为与指示一致性。

**边界：**有线原型证明的是交互，不代表解决了所有耳机的蓝牙多点兼容。不能假设普通 MCU 能在 48h 内重写商用耳机固件。

### F. 可维护的传感器供电底座

**改造对象：**温湿度、门窗等低功耗传感器。对应证据 24—26 及 AHS 调查。

**功能：**电池仓可打开更换；允许 USB 供电；低电量提前报告；接收端区分“最近一次检测正常”“低电量”“长时间未收到心跳”，避免把无数据当正常。

**48h 范围：**在自制或开放硬件传感节点上做一套供电底座；验证低电压、断网、换电池后数据保留。使用模拟或可调电源验证阈值，不把加速演示当成长续航实测。

**边界：**不同传感器的电压、尺寸与接口不同，不能宣称一个底座兼容所有旧设备。可换电池已有产品，例如 Fairbuds；应把维护方式作为具体产品迭代。[Fairphone 更换指南](https://support.fairphone.com/hc/en-us/articles/17676882282258-Fairbuds-spare-parts-replacement-guide)

### G. 尊重手动操作的自动灯

**改造对象：**自动感应台灯/落地灯。对应证据 27—28。

**功能：**旋钮有“自动/保持/关闭”三个明确位置；坐着不动时，座椅压力传感器为保灯条件；手动调整后自动规则不立刻覆盖。什么时候返回自动模式由旋钮或明确的退出条件决定。

**48h 范围：**一盏低压灯、座椅压力传感器、PIR、三挡开关与本地状态机。

**验证：**坐着不动、起身短暂离开、手动关闭后有人经过、设备重启。手动关灯后被动传感事件不得立即重新打开。

**边界：**手动优先已有实现；本项目的迭代重点是可见的模式与可解释的返回条件，不要包装为全新传感技术。

### H. 可见的隐私开关

**改造对象：**USB 摄像头、联网音箱的隐私控制。需求依据是 AHS 的隐私担忧数据，未计入 31 个社区主题的统计。

**功能：**机械遮挡镜头，并用位置检测确认遮挡到位；麦克风关闭由真实硬件电源/信号通路控制，标识与实际状态关联。

**48h 范围：**先给一台 USB 摄像头做手动遮挡附件与状态指示；若进一步做传感器断电，需针对明确硬件电路验证。两种能力分别演示，不把遮镜头描述成禁用麦克风。

**边界：**机械遮挡已有大量产品。可探索共享空间中“谁开启、当前是否遮挡、什么时候恢复”的明确交互，但不得声称硬件附件保证全部网络隐私。

## 四、建议的选题顺序

| 项目 | 适合的团队倾向 | 首个必须通过的验证 |
|---|---|---|
| 有回执的实体遥控器 | 嵌入式 + 物联网的均衡选题 | 发出命令与真实执行能可靠区分 |
| 带保活口的供电座 | 熟悉电源路径与硬件测量 | 关键负载在实际插拔时不复位 |
| 暗夜状态贴 | 希望快速改造现有物品、突出生活体验 | 遮光与读取状态同时成立 |
| 家电待处理状态贴 | 擅长传感器融合与状态机 | 暂停、结束、开门和下一轮不混淆 |

前三者可直接带现有物品上台演示。选择前可用约 2 小时完成单个关键机制，并邀请 5 位目标用户实际操作；记录成功与失败，而不是仅询问“喜不喜欢”。验证任务应有前后对比，例如传统遥控器失败时用户能否察觉、状态贴是否减少被亮灯打扰、保活接口是否防止复位。

## 五、31 个社区主题证据索引

“正文”表示本轮打开页面并核对了相关内容；“摘录”表示采用搜索工具公开返回的相关摘录，未逐楼核查。标题作简化标识；表内均为转述，不把评论者技术解释当成已证实原理。

| 编号 | 主题/来源 | 具体诉求 | 阅读范围 |
|---|---|---|---|
| 01 | [离线语音控制，V2EX](https://www.v2ex.com/t/1017274) | 网络错误妨碍关空调，期望本地响应 | 正文 |
| 02 | [全无线智能家居稳定性，V2EX](https://www.v2ex.com/t/1069561) | 掉线、本地控制与维护负担 | 摘录 |
| 03 | [从遥控到自定义智能，V2EX](https://www.v2ex.com/t/1065064) | 品牌系统不通、逐个 App 配网复杂 | 摘录 |
| 04 | [智能家居烦恼与愿望，Reddit](https://www.reddit.com/r/smarthome/comments/1ksb3p3) | 多生态、可靠性、换电池、实体开关等多类意见 | 正文 |
| 05 | [仅 App/触摸控制的家电，Reddit](https://www.reddit.com/r/Appliances/comments/1jpjk9s/) | 需要实体入口，担心软件支持终止；发帖者亦在开发开源厨房电器，保留这一背景 | 正文 |
| 06 | [灶具操作界面吐槽，Reddit](https://www.reddit.com/r/Cooking/comments/sco626) | 逐次点击调节不如旋钮直接 | 摘录 |
| 07 | [触屏与无障碍，Reddit](https://www.reddit.com/r/AccessibleAnarchy/comments/1volrbx/touchscreen_buttons_vs_physical_buttons_on/) | 需要能靠触摸定位的控制件 | 摘录 |
| 08 | [多口充电器吐槽，V2EX](https://www.v2ex.com/t/845887) | 插拔相关断电影响持续供电场景 | 摘录 |
| 09 | [多口氮化镓充电器咨询，V2EX](https://www.v2ex.com/t/908394) | 手机与电脑同时接入时反复断流 | 摘录 |
| 10 | [多设备充电问题，V2EX](https://www.v2ex.com/t/812142) | 关注多接口同时使用时是否闪断 | 摘录 |
| 11 | [征集不掉电充电器清单，Reddit](https://www.reddit.com/r/UsbCHardware/comments/1c0ljdm/datapoints_welcome_list_of_usbc_gan_chargers_that/) | 社区专门收集插拔不影响已有设备的产品 | 正文 |
| 12 | [多口 GaN 插拔握手，Reddit](https://www.reddit.com/r/UsbCHardware/comments/1w70bvf/multiport_gan_chargers_handshakes_on_disconnection/) | 2026 年仍有用户寻找不闪断的型号 | 摘录 |
| 13 | [寻找不中断供电的充电器，Reddit](https://www.reddit.com/r/UsbCHardware/comments/1roxfy3/looking_for_a_multiport_usb_charger_that_doesnt/) | USB 供电设备因其他端口插拔而重启 | 摘录 |
| 14 | [AirPods 多设备切换，V2EX](https://www.v2ex.com/t/1023356) | 自动抢声音与手动切换麻烦的取舍 | 正文 |
| 15 | [妙控板两电脑切换，V2EX](https://www.v2ex.com/t/843951) | 断开重连成本高，需要明确切换入口 | 摘录 |
| 16 | [寻找按键切换音源的耳机，Reddit](https://www.reddit.com/r/bluetooth/comments/xrdigp/iso_bluetooth_headphones_that_can_switch_easily/) | 想用实体按钮选择已配对设备 | 正文 |
| 17 | [多点连接体验，Reddit](https://www.reddit.com/r/SonyHeadphones/comments/18kmr7i) | 手机与电脑组合下切换不稳定 | 摘录 |
| 18 | [耳机多点连接吐槽，Reddit](https://www.reddit.com/r/bose/comments/1b6hqzw/it_is_honestly_atrocious_how_bad_the_multipoint/) | 切换、连接或音频异常 | 摘录 |
| 19 | [微波炉提示音能否关闭，Reddit](https://www.reddit.com/r/Appliances/comments/1k62s8h/why_dont_microwaves_let_owners_turn_off_the_beep/) | 希望能方便地关闭普通蜂鸣 | 正文 |
| 20 | [洗衣机烘干机重复蜂鸣，Reddit](https://www.reddit.com/r/Appliances/comments/vv9r61/ge_front_load_washer_and_dryer_does_anyone_know/) | 结束后反复提示造成打扰 | 摘录 |
| 21 | [用胶带遮指示灯，Reddit](https://www.reddit.com/r/mildlyinfuriating/comments/11j5zcb) | 卧室设备状态灯过亮，依赖遮挡 | 摘录 |
| 22 | [旅行携带遮光胶带，Reddit](https://www.reddit.com/r/LifeProTips/comments/1e6p9n2/lpt_if_you_travel_bring_some_electrical_tape_to/) | 住宿环境中难以关闭的设备灯光 | 摘录 |
| 23 | [指示灯设置不能保持，Reddit](https://www.reddit.com/r/BadDesigns/comments/1msyk40/led_lights_on_electronics_is_a_scourge_on_this/) | 关闭后再次亮起，设置缺乏可靠性 | 摘录 |
| 24 | [耳机换电池还是换新，V2EX](https://v2ex.com/t/746127) | 电池老化后维修与换新成本接近 | 摘录 |
| 25 | [寻找可换电池耳机/DAC，Reddit](https://www.reddit.com/r/headphones/comments/19fa8ef) | 期望用户可维护电池 | 摘录 |
| 26 | [寻找可自行换电池的耳塞，Reddit](https://www.reddit.com/r/Earbuds/comments/1qy03ld/wireless_earbuds_with_userreplaceable_batteries/) | 自行拆换电池失败，希望设计支持维修 | 摘录 |
| 27 | [运动触发后保持灯亮，HA 社区](https://community.home-assistant.io/t/option-to-leave-light-on-after-motion-detected/169871) | 办公时需要手动保持照明 | 摘录 |
| 28 | [手动亮灯与自动关灯冲突，HA 社区](https://community.home-assistant.io/t/turn-lights-on-off-with-motion-but-only-if-not-already-on/49610) | 自动化误关人为开启的灯 | 摘录 |
| 29 | [洗衣提醒过度触发，HA 社区](https://community.home-assistant.io/t/washer-alert-works-too-well-please-help-make-it-smarter/388616) | 下一轮启动后仍收到上一轮完成提醒 | 摘录 |
| 30 | [持续洗衣提醒，HA 社区](https://community.home-assistant.io/t/repeating-laundry-notification-with-time-in-laundry-machine-updates/74538) | 完成后按是否到家、等待时间再提醒 | 摘录 |
| 31 | [家电提醒与门磁状态需求，HA 社区](https://community.home-assistant.io/t/appliance-notifications-actions-washing-machine-clothes-dryer-dish-washer-etc/650166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) | 希望区分空闲、运行、完成待清空和复位 | 摘录 |

## 六、还需要验证的问题

- 五名目标用户能否确认上述具体困扰，并在没有引导的情况下使用原型？这用于选题，不足以推算市场规模。
- 现有设备是否提供可用协议、状态输出或可观测信号？闭源协议和无法观测的状态会直接改变范围。
- 产品改进的价值是否超过新增节点、配对、换电池和校准带来的维护成本？尤其是状态贴，要把这一点作为实测问题。
- 团队应把“当前原型已验证”“仅在特定型号适用”“未来扩展”分开展示。

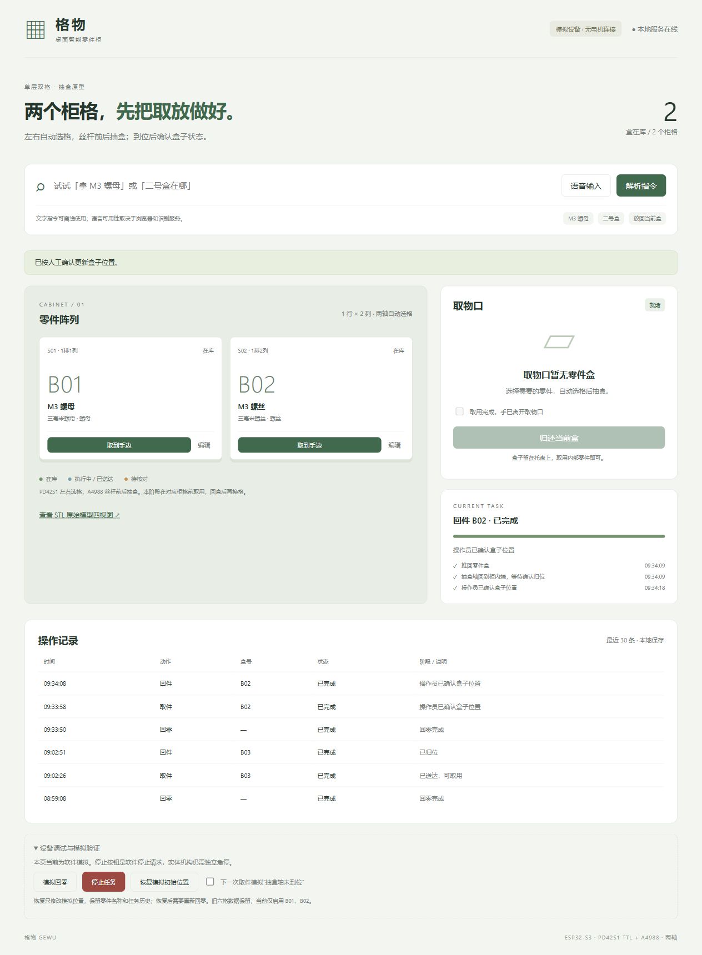
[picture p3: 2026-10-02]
docs/two-slot-preview.jpg

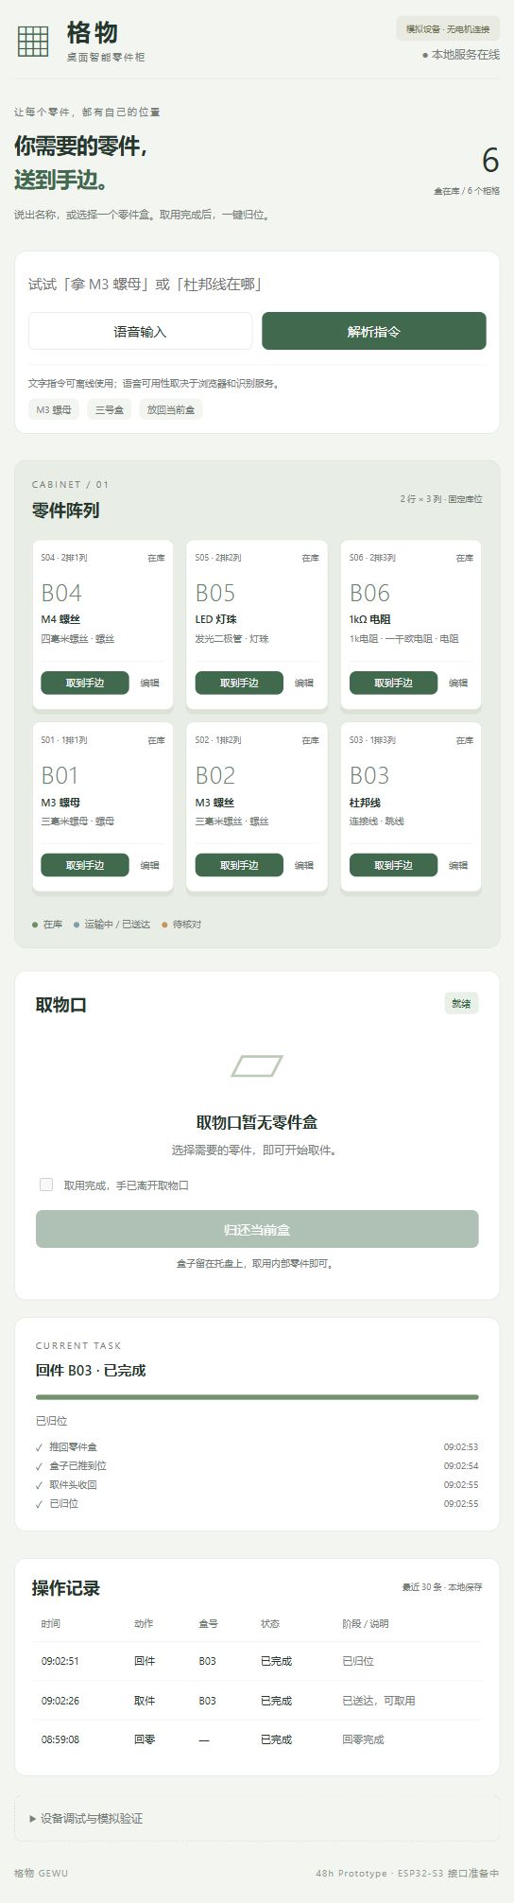
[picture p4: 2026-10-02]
docs/demo-preview.jpg

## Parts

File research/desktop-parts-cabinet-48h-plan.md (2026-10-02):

# 桌面智能二维抽屉阵列式零件柜：方案与 48h Demo 实施清单

日期：2026-10-01。设计草案，尚未完成实物验证。

## 1. 产品目标与实施前提

用户说出零件名称，系统找到对应编号的零件盒，自动取出并送到固定取物口；用户拿取或补充零件后，系统将盒子送回原柜格，并记录任务结果。

48h 以“六格柜、一盒在外、原位归还、取放闭环”为目标。暂按四人团队、有基础电子模块和快速加工条件设计；如果零件需要远程采购或从零加工全部运动结构，48h 风险明显增加，应优先复用现成模组。

- 柜体：2 行 × 3 列；首个可运行版本为 2 × 2，仍能证明二维寻址。
- 盒子：统一尺寸、统一取放接口、每盒一个零件品类，固定柜格。
- 起始打样参考：盒体宽 80 × 深 100 × 高 50 mm；单盒含零件质量目标不超过 200 g。这是限制设计范围的建议值，不是承载认证。
- 取物方式：盒子停在机器人托盘上，用户取出零件或补充零件，然后点击/说“放回当前盒”。首版不要求用户搬走整个盒子。
- 一次只允许一个盒子处于取出状态；它回柜前拒绝下一次取盒请求，并说明当前盒号。
- 不自动判断零件数量。盒子在库与零件剩余数量分别管理，数量若加入则由用户确认。

价值表达：把“记住位置、寻找零件、搬取盒子、归位”变成“说出名称、在固定窗口取用”。准确选择与可靠归位共同构成演示价值。

## 2. 机械方案

### 2.1 机构组成

| 子系统 | 建议方案 | 关键约束 |
|---|---|---|
| X 左右定位 | 步进电机 + 同步带 + 直线导轨，带动竖直模组 | 滑轨只负责导向，必须另有同步带或丝杆驱动 |
| Z 上下定位 | 步进电机 + 丝杆螺母 + 独立导轨，带动托盘 | 丝杆负责驱动，导轨承担偏载；按托盘、伸缩机构、盒子总质量选型 |
| E 前后取放 | 短行程线性模组，推动可伸缩拉钩和推板 | 有效行程必须覆盖盒子从柜内到完全离柜所需位移 |
| 拉钩开合 | 小舵机旋转钩爪，配盒子前部标准拉环 | 舵机仅开合钩爪，盒子重量由托盘承受 |
| 运输承托 | 固定在 Z 滑台上的托盘 | 托盘要托住整个盒底，带侧向限位及防滑出挡边 |
| 柜格 | 固定搁板、侧导向、入口倒角、末端止挡 | 盒子必须能完全抽离；普通抽屉的防脱扣需提前处理 |
| 取物口 | 阵列旁边、用户易触及的固定位置 | 托盘直接停靠，且取物口处于 X/Z 行程内 |

空间关系：柜体在后，X/Z 机构在柜体前方，E 轴沿柜体深度伸缩。前方必须预留盒子完整退出及随托盘移动的空间。柜体宽高不能直接当成整机外形尺寸，还要加取物口、模组和维护余量。

示意：

```text
正视图（柜格在后，移动托盘在前）
┌────────┬────────┬────────┐
│ S04/B04│ S05/B05│ S06/B06│
├────────┼────────┼────────┤
│ S01/B01│ S02/B02│ S03/B03│   [固定取物口]
└────────┴────────┴────────┘
             X 左右 / Z 上下

侧视图
后方 [柜格内的盒子] ← E 推回 / E 拉出 → [承托托盘] 前方
```

### 2.2 最先验证的结构细节

1. **标准接口**：每个盒子前方安装同样高度的拉环或卡槽；拉钩带导入斜面和少量装配调整余量。必须同时设计拉出与推回的受力面。
2. **连续支撑**：盒子从搁板滑到托盘时，底面始终有支撑。缩小柜体与托盘的间隙，用短过渡舌片/倒角避免盒底前缘卡住；应实测双向过渡。
3. **完全离柜后移动**：E 收回到运输位，盒子后缘已离开柜格与立柱，才能允许 X/Z 运动。不能只检测到盒子前端就认为已取出。
4. **推回后可靠脱钩**：推板把盒子推到标定深度，盒子由柜格的轻阻尼定位结构保持；钩爪打开后空载退回，不得把盒子再次拖出。
5. **稳定性与重心**：前伸托盘会形成倾覆力矩，底座固定或配重；Z 机构考虑失电下滑，不能默认任意丝杆都有自锁能力。

首选机械钩爪与承托托盘。磁吸方案只有在已经验证拉力、对位和释放机构时采用，否则“吸住容易、释放困难”会增加联调工作。

### 2.3 尺寸与标定

使用 S01 等柜格 ID、B01 等盒 ID，避免将固定位置和可移动物体混为同一个编号。

规则阵列初值：

```text
x = x0 + column × pitch_x + correction_x[slot]
z = z0 + row    × pitch_z + correction_z[slot]
```

行列从 0 开始。允许每格独立微调，实际制造偏差不应依赖全局间距公式消除。配置还包括 E 运输位、各格对接深度、取物口位置、速度和加速度上限。

盒子行程、托盘长度、拉钩长度先通过单格样机确定，再冻结柜格间距。不要先加工整柜再修改取放接口。

## 3. 硬件与控制

### 3.1 首版物料清单

| 物料 | 数量 | 选择依据 |
|---|---:|---|
| 统一零件盒 | 4–6 | 滑动顺畅、无不可移除防脱结构 |
| 柜架、搁板、底座 | 1 套 | 刚度、导向一致性和固定能力 |
| X 同步带直线模组 | 1 | 行程覆盖所有列和取物口 |
| Z 丝杆直线模组 | 1 | 行程覆盖所有行及取物口高度，承载按整个移动总成计算 |
| E 短行程线性模组 | 1 | 行程按完整抽盒距离验证 |
| 步进电机及驱动 | 通常各 3 | 优先模组配套；电流、电压、转速转矩需匹配 |
| 拉钩舵机、推板、托盘 | 各 1 | 舵机只承担钩爪动作，拉推负载由 E 轴承担 |
| ESP32 或团队熟悉的 MCU | 1 | USB 串口通信，有足够电机/限位/传感器接口 |
| 轴回零开关 | 每轴至少 1 | 推荐另加另一端限位；布线和消抖须验证 |
| 托盘盒子到位传感器 | 1 | 安装位置应能区分完全到托盘与刚进入托盘 |
| 对接确认传感器 | 1 | 可装在取件器上，验证盒子是否推到最终位置 |
| 实体急停、取物确认按钮 | 各 1 | 急停直接作用于运动使能/电源回路，不能依赖网页 |
| 电机电源、逻辑/舵机稳压电源 | 1 套 | 按实际驱动需求核算并留余量；舵机不要直接依赖主控小电源 |
| 笔记本、麦克风、USB 线 | 1 套 | 运行界面、后端、语音识别，减少嵌入式端工作量 |

不在模组未确定前给出精确采购价格或电机转矩。先确认库存、额定载荷和拉出阻力，再确定型号；“NEMA17/42 步进”只说明安装尺寸类别，不能单独说明承载能力。

若使用 DRV8825，按实际板卡资料设置限流并处理散热、近端去耦。Pololu 官方载板资料给出供电范围及其载板的散热条件；兼容板的采样电阻可能不同，不能直接照搬 VREF 换算。[官方资料](https://www.pololu.com/product/2133/)

### 3.2 控制分工

- **PC 后端**：零件查询、盒格映射、任务互斥、日志、界面同步、语音意图校验。
- **MCU**：步进脉冲、加减速、回零、限位、传感器、动作顺序和运行互锁。
- **通信**：优先 USB 串口，按行传输小型 JSON。48h 首版无需增加 Wi-Fi/MQTT 依赖。
- **运动代码**：采用团队已有、验证过的运动驱动或库，动作状态机非阻塞，持续响应急停及限位。
- **可替代方案**：若已有调通的 CNC 控制板与 Grbl，复用其运动能力，另解决舵机和传感器编排；不要同时新开发两套固件。

Grbl 的命令 `ok` 不代表物理运动已经完成，执行器适配层还需确认运行状态并结合传感器判断。原始 Grbl 接口与本方案的任务 JSON 是两层协议，不能直接混用。[Grbl 官方接口文档](https://github.com/gnea/grbl/wiki/Grbl-v1.1-Interface)

### 3.3 必须实现的互锁

- 未回零/坐标不可信时禁止自动取放。
- E 未处于完整收回的运输位时，禁止 X/Z 运动。
- 已有盒子在外或托盘被占用时，拒绝新取盒任务。
- 对接位之外禁止 E 伸出；所有目标坐标经过行程范围检查。
- 取物时 X/Z/E 静止，用户确认手离开操作区后才允许回柜；首版为有人值守演示。
- 限位异常、传感器矛盾、阶段超时、通信丢失均停止继续执行；故障不能直接标记为完成。
- 实体急停结合垂直轴防坠设计。软件暂停不是实体急停的替代。
- 断电、急停或运动中断后进入 RECOVERY_REQUIRED。先人工检查盒子是否横跨柜格和托盘，再决定恢复路径；不可盲目先回零。

## 4. 取件、回件与状态模型

### 4.1 取件流程

1. 用户从网页或语音选择零件；后端解析到唯一盒号、柜格。
2. 校验设备已就绪、托盘为空、盒子在库、无其他未归还盒；创建任务并锁定设备及盒格。
3. E 确认位于运输位；X/Z 移动到标定柜格坐标。
4. E 伸出对接，舵机闭合拉钩，E 将盒子拉到托盘。
5. 验证 E 已收回且盒子完全到托盘，否则停止并报告阶段故障。
6. X/Z 将托盘送到固定取物口并停止。
7. 后端将盒位置改为 PRESENTED，任务完成；界面显示“B03 已送达，可取用”。

### 4.2 回件流程

1. 用户取用结束，点击/说“放回当前盒”，并确认操作区已让开。
2. 校验当前盒仍在托盘，原柜格保留给该盒；禁止现场把其他盒子放进其保留格。
3. E 保持收回，X/Z 返回原柜格。
4. E 推入盒子，确认对接深度和就位传感器，打开拉钩，空载退回。
5. 确认 E 收回、托盘为空；后端将盒位置改为 STORED，解除保留状态。
6. 托盘返回停靠位，记录任务完成。

### 4.3 三类状态要分开

```text
设备：UNHOMED → HOMING → READY → BUSY → READY
异常：任意执行状态 → FAULT / RECOVERY_REQUIRED

盒子：STORED → IN_TRANSIT → PRESENTED → IN_TRANSIT → STORED
异常：位置不能确认时 → UNKNOWN

任务：QUEUED → RUNNING → SUCCEEDED / FAILED / INTERRUPTED
```

P0 可不开放真正的等待队列：设备忙就拒绝新请求。一个取件任务送达即成功，但整个设备仍因“已有盒在外”而限制下一次取件，允许查询和回件。

物理操作中断时不能把数据库事务回滚解释为盒子已回到原位。保留最后确认位置和失败阶段，标为待恢复。

## 5. 后端、界面与语音

### 5.1 最小软件栈

建议使用团队最熟悉的 Web 技术。没有既有项目时可采用 Python 后端 + SQLite + 单页 Web 界面；运动放在 MCU，语音识别运行在 PC 或通过已有服务完成。

界面保留四个区域：

1. 零件搜索、名称与别名编辑、取件按钮。
2. 与实物一致的 2 × 3 柜格图：盒号、零件名、位置状态。
3. 当前任务：识别文本、目标盒、执行阶段、成功/故障信息。
4. 当前取物口：盒号、回件按钮、手动恢复入口。

工程调试页面另放回零、单轴点动、坐标标定和传感器状态。普通用户只看到取用过程。

### 5.2 最小数据结构

| 对象 | 字段 |
|---|---|
| parts | id, name, aliases；首版每盒对应一个品类 |
| slots | id, row, column, x_mm, z_mm, e_dock_mm |
| boxes | id, part_id, home_slot_id, location_state, last_confirmed_location |
| tasks | id, request_id, action, box_id, status, phase, error, created_at, finished_at |
| task_events | task_id, sequence, phase, sensor_snapshot, timestamp |
| device_config | 回零参数、行程、速度、加速度、取物口坐标、标定版本 |

约束：同一柜格只绑定一个盒子；同一设备只运行一个任务；同一个 request_id 不重复执行。任务完成后再更新“已送达/已归位”，命令 ACK 仅表示已接收。

### 5.3 建议接口

```text
GET   /parts?query=...
PATCH /parts/{id}             编辑名称和别名
GET   /cabinet                柜格、盒子与当前设备状态
POST  /tasks                 action=FETCH/RETURN, box_id, request_id
GET   /tasks/{id}             查询实际执行阶段
POST  /voice/interpret        返回文本、意图、候选盒、是否需用户选择
GET   /device/status
POST  /device/home            仅在满足恢复条件时允许
```

实时进度采用 WebSocket/SSE；若团队实现不熟悉，短间隔轮询已足够支持六格 Demo。

串口自定义任务例：

```json
{"type":"command","task_id":"T001","cmd":"FETCH","slot_id":"S03","config_version":1}
{"type":"ack","task_id":"T001","accepted":true}
{"type":"event","task_id":"T001","seq":2,"phase":"BOX_ON_TRAY"}
{"type":"result","task_id":"T001","success":true,"location":"PICKUP"}
```

MCU 用配置表将 slot_id 转成坐标。PC 与 MCU 标定版本不一致时拒绝动作。重复 task_id 返回当前状态；断线后查询，禁止盲目重发运动命令。MCU 重启后即使丢失去重缓存，也要因未回零/待恢复而禁止直接执行旧任务。

### 5.4 语音边界

固定支持四类指令：

- “拿 M3 螺母” → FETCH，唯一匹配到盒子。
- “拿三号盒” → FETCH B03，支持数字别名。
- “放回当前盒” → RETURN 当前已送达盒。
- “杜邦线在哪” → QUERY，返回柜格和盒状态。

流程：按住说话 → 语音转文字 → 动作及零件名称抽取 → 数据库匹配 → 业务校验 → 创建任务。

首版只需词典、别名与模板匹配。若使用大模型，把输出限制为动作枚举和候选零件 ID，再由后端校验；模型不得产生可直接执行的电机坐标或任意命令。

“拿螺丝”同时匹配 M3/M4 时展示两个候选，让用户选；识别失败就显示转写文本并允许修正。第一次 Demo 可以统一显示“即将取 B03”确认，降低噪声环境下的误触发。

语音识别实际成功是语音功能的验收条件。预设文本按钮只作备用输入，不能把它描述成现场语音识别。断网影响语音服务时，网页取放仍应可运行。

## 6. 48h 范围取舍

| 等级 | 内容 | 完成标准 |
|---|---|---|
| P0 必做 | 二维阵列定位 | 至少 2 × 2 格实际寻址，目标 2 × 3 |
| P0 必做 | 自动取盒及回盒 | 完整拉上托盘、送到取物口、推回原格 |
| P0 必做 | 位置和动作验证 | 回零、E 收回、托盘到位、回柜确认、超时处理 |
| P0 必做 | 后端持久化 | 零件名/别名、盒号、固定柜格、位置状态、任务日志 |
| P0 必做 | 网页入口 | 搜索、取件、回件、实时阶段与故障显示 |
| P0 必做 | 有限语音控制 | 至少三种零件名称的取件及“放回当前盒” |
| P0 必做 | 运行约束 | 单盒互斥、重复请求去重、失败不报成功、实体急停 |
| P1 余量再做 | 语音播报、灯效 | 与实际状态一致 |
| P1 余量再做 | 手工库存数量 | 用户确认增减，不从盒子存在推断零件数量 |
| P1 余量再做 | 盒子二维码核验 | 用于允许用户整盒拿走后的身份核对 |
| P2 后续 | 多盒在外、动态库位 | 要增加身份核验、缓存位置和调度规则 |
| P2 后续 | 自动称重计数、视觉识别 | 另行验证精度与适用范围 |
| P2 后续 | 传送带、手机 App、多人权限 | 本次无需增加这些系统 |

托盘存在传感器只能确认有盒，不能证明它是 B03。因此 P0 规定盒子留在托盘上，且只有一个盒在外。若演示要求整盒搬离设备，就必须增加“归还时确认盒号”的流程，二维码可作为后续实现。

## 7. 四人分工与进度门槛

分工：A 机械/加工；B 电控/固件；C 后端/通信；D 界面/语音/演示。并行由团队成员执行，机械与电控应共同负责取放机构验收。

| 时间 | A 机械 | B 电控 | C 后端 | D 交互 | 必须交付 |
|---|---|---|---|---|---|
| H0–H2 | 确认盒子、拉钩和托盘空间 | 确认现成模组与接口 | 定义状态和串口协议 | 确定页面和演示用零件 | 冻结范围、盒格编号、接口契约 |
| H2–H8 | 单格样机、手动拉推验证 | E 轴及舵机、传感器 | 数据表、任务互斥、模拟设备 | 柜格页面、麦克风采集验证 | 单格机械取放能成立 |
| H8–H16 | 柜体及 X/Z 装配 | 回零、单轴点动、限位 | 串口接入、日志、去重 | 页面接真实后端、语音匹配 | 单格电动取回连续 10 次 |
| H16–H24 | 全部柜格校准 | 完整取放状态机 | 真实任务回执更新状态 | 网页端到端取回 | 至少两个不同柜格真实闭环 |
| H24–H32 | 修正卡顿、拖链/布线 | 多格稳定性及故障处理 | 重连与恢复、持久化核对 | 语音接入同一任务接口 | 语音真实取盒和回盒 |
| H32–H40 | 稳定性修整 | 连续循环及异常验证 | 修复状态不一致 | 提示、演示脚本、录像 | 功能冻结，完成验收记录 |
| H40–H48 | 固定结构及备用件 | 不再改运动架构 | 仅修阻断故障 | 彩排、讲解、备用输入 | 可复现演示与备份视频 |

硬门槛：

- **H8**：单格拉出/推回仍不顺畅，立即修改盒接口和过渡面，暂停外观加工。
- **H16**：单格自动取回不稳定，削减到 2 × 2，并缩小重量与速度范围，保留完整闭环。
- **H24**：必须有真实硬件端到端流程，不能只有模拟器与独立电机测试。
- **H32**：停止增加新功能，优先修复卡盒、脱钩、状态错误和识别歧义。

若到最后仍只能人工把盒子放上托盘，应如实称为“定位与输送原型”，不能宣称自动取放已经完成。

## 8. 验收与演示

### 8.1 验收目标（待实测）

- 六个目标柜格各完成至少 3 次完整取回循环；另外进行至少 10 次混合柜格连续循环，记录干预次数、卡盒和错盒。
- 最终彩排连续 10 次不需要人工扶盒或纠偏；未通过时优先修机械对接，不能只补界面动画。
- 起始速度目标：单次从确认取件到送达 15–30 秒；以实际行程与承载测试调整，不把目标写成实测结果。
- 3 种零件名称各试 3 次语音取件，另外测试回件和一个有歧义的名称；记录识别正确、候选选择及失败次数。
- 重复点击/相同 request_id 不产生第二次物理动作。
- 当前盒未归还时，取下一盒被明确拒绝。
- 模拟拉空、未收回到位或回柜未确认时，系统不继续运输、不显示完成。
- 串口断连、设备重启后界面进入待恢复，盒子状态不被自动重置成在库。
- 实体急停能停止动作；复位后需明确恢复流程，不自动续跑。
- 后端重启后仍保留零件名称及映射；若执行中断，保留未决任务并要求核对物理位置。

计时拆分语音识别耗时与机械运输耗时，便于知道应该优化哪里。用运行记录描述演示稳定性，不能将少量样机测试当成产品可靠性认证。

### 8.2 约三分钟演示脚本

1. 15 秒：说明小零件多、位置难记、归还易乱的使用问题。
2. 20 秒：展示六格实体柜与对应管理界面，介绍盒号和零件名称映射。
3. 40 秒：说“拿 M3 螺母”，界面显示识别及匹配结果；真实机构取盒、送达。
4. 20 秒：取出一颗零件，展示盒子仍在托盘上，以及系统的已送达状态。
5. 35 秒：说“放回当前盒”，确认操作区已让开，机器回到原格完成归位。
6. 25 秒：展示歧义选择或重复请求防护中的一个真实能力。
7. 25 秒：展示操作日志，说明已经完成的能力和下一步扩展。

演示顺序以现场机械耗时调整。准备真实成功流程录像及网页备用入口，明确说明何时用了备用方式。

## 9. 第一小时即可分派的任务

1. 找到六个相同盒子，测尺寸、含物料重量和手动抽拉阻力，拍照记录接口。
2. 在纸上画出柜格—托盘侧剖面，确认抽出全过程的支撑和完全退出后的空间。
3. 用一个柜格、一个托盘和拉钩做单格样机；取出与放回都验证后再复制。
4. 软件建立 B01–B06、S01–S06 和三种演示零件，创建网页按钮到模拟设备的任务链路。
5. 固件与后端共同确定 task_id、ACK、phase、result、error 的含义，按上面的状态模型实现。

## 10. 参考资料与适用范围

- [Pololu DRV8825 官方载板资料](https://www.pololu.com/product/2133/)：驱动供电、限流、散热与布线注意点。具体数值须与实际采购的驱动板匹配。
- [Grbl 1.1 官方通信接口](https://github.com/gnea/grbl/wiki/Grbl-v1.1-Interface)：命令响应、执行状态与状态查询，用于复用 Grbl 时设计适配层。
- [Grbl 官方回零设置](https://github.com/gnea/grbl/wiki/Set-up-the-Homing-Cycle)：回零及限位配置参考。此柜体带抽盒机构，回零前仍必须满足本机的机械避碰条件。

上述资料支持元件和控制接口说明；柜体结构、尺寸、任务划分及工期为本项目的设计建议，尚须通过样机验证。

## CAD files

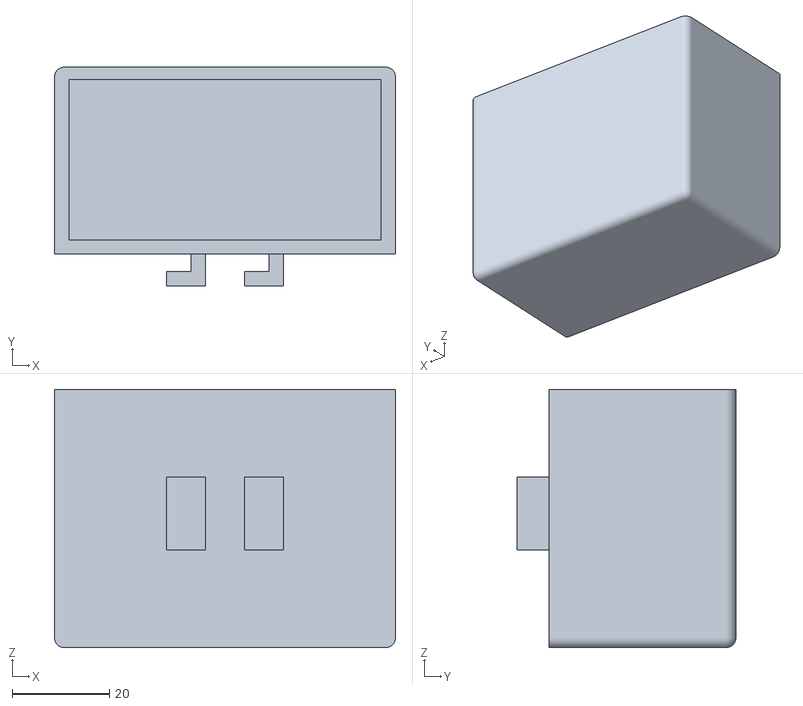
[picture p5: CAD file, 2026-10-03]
models/盒子及钩件1.stl
70.0 x 44.9 x 53.0

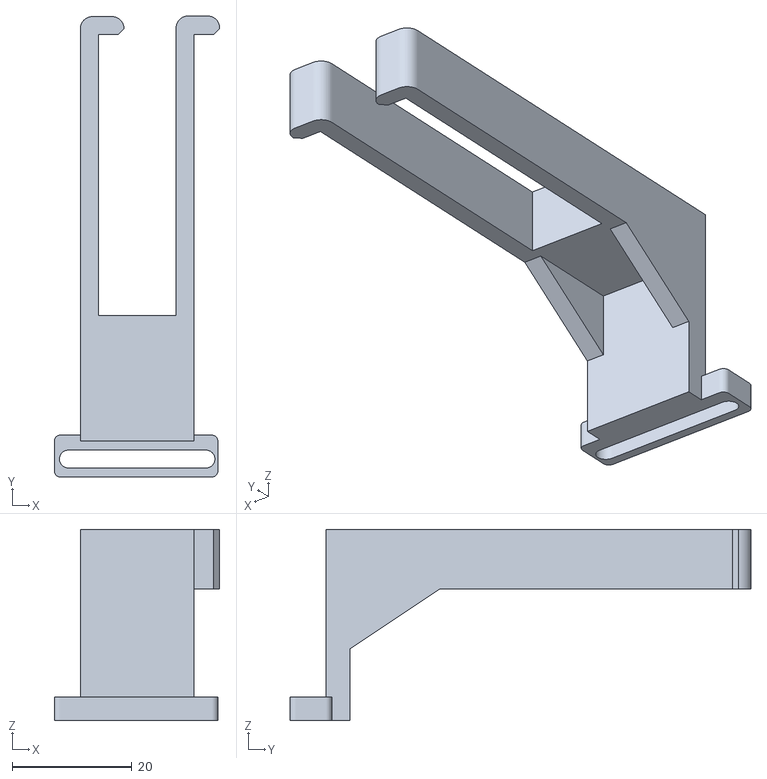
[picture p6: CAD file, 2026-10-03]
models/钩.stl
27.7 x 77.1 x 32.0

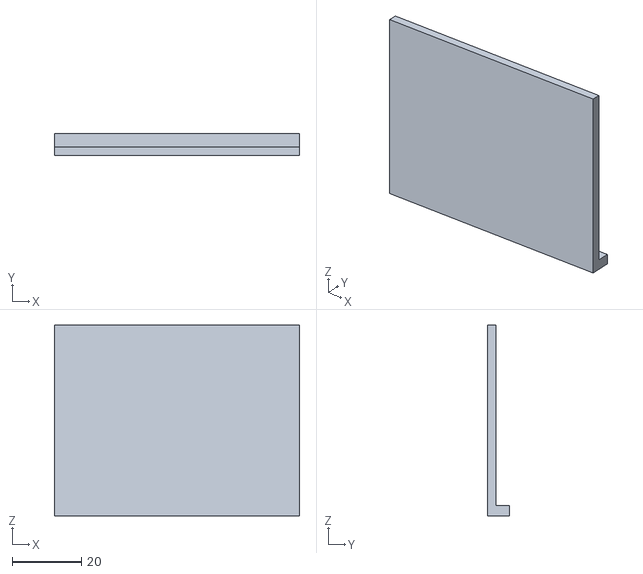
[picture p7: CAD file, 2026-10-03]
models/卡板.stl
70.7 x 6.30 x 55.0

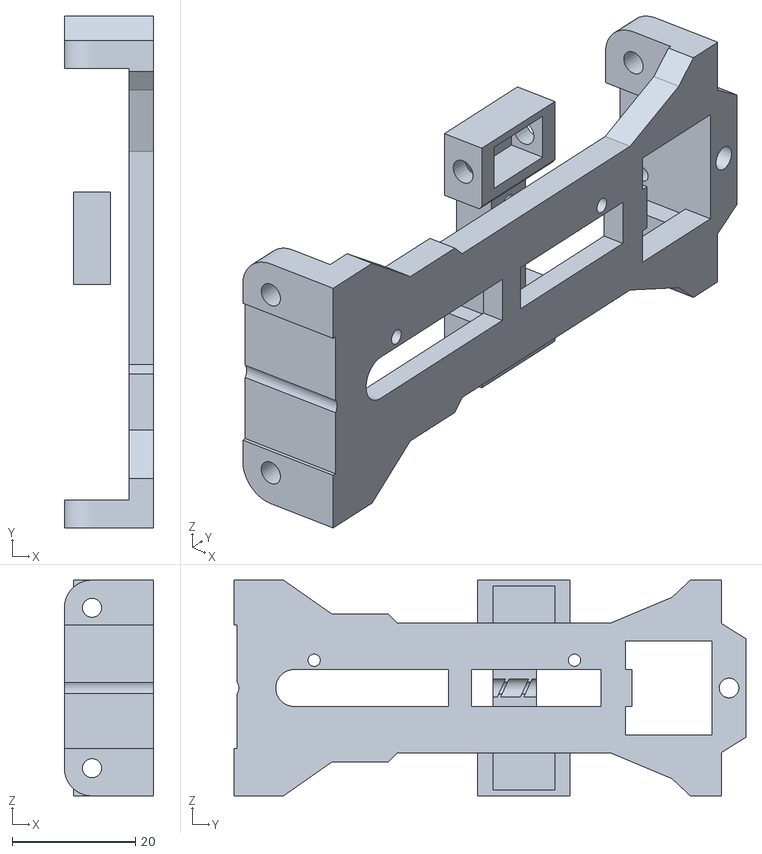
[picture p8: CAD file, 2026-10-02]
models/E轴电机槽.stl
14.5 x 83.0 x 35.0

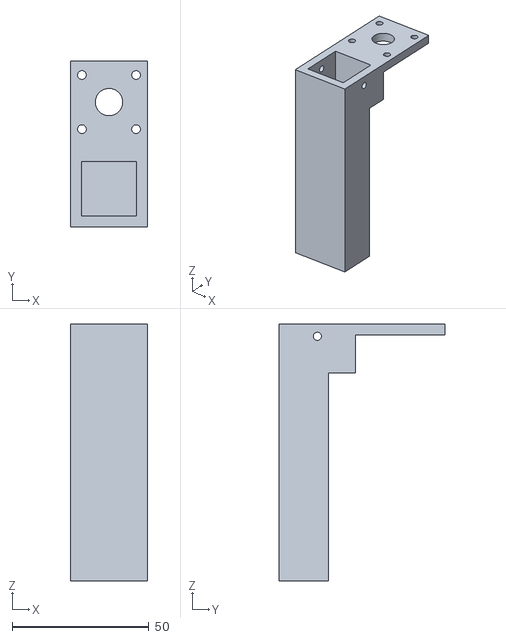
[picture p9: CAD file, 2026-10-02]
models/减速电机固定.STL
28.0 x 60.6 x 94.0

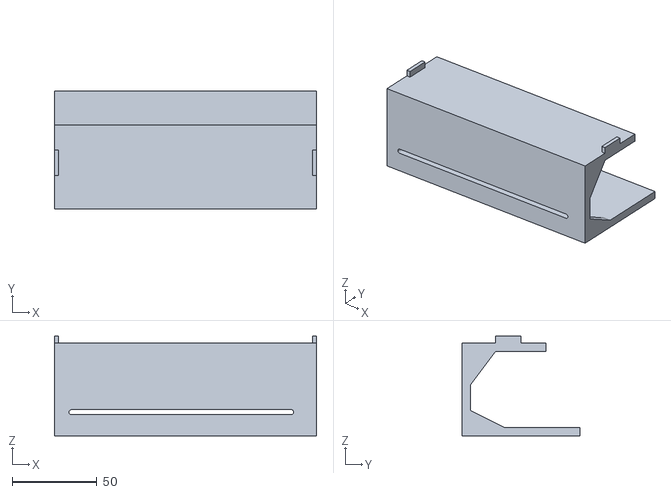
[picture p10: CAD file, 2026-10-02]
models/底座.stl
155.0 x 70.0 x 59.0

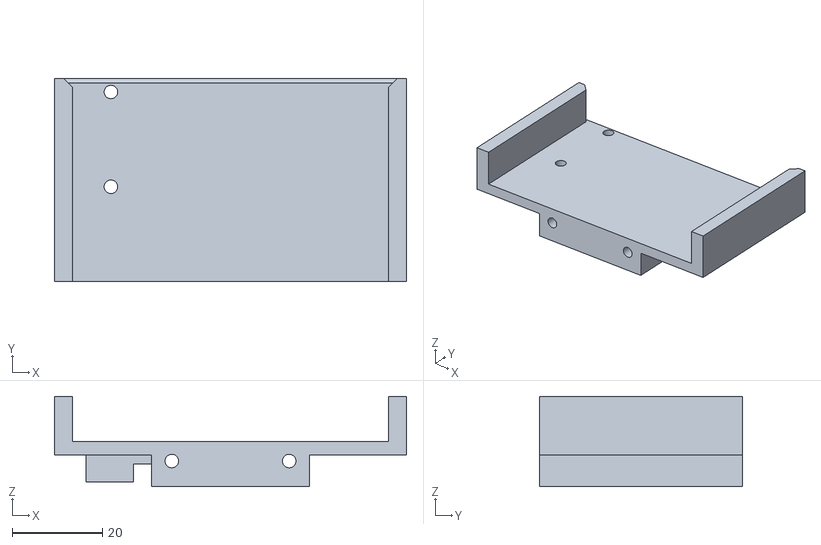
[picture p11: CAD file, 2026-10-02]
models/托盘.STL
78.0 x 45.0 x 20.0

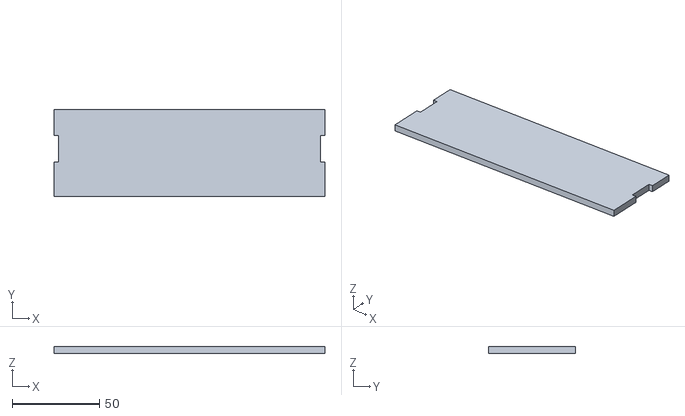
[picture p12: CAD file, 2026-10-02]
models/顶板.stl
155.0 x 49.9 x 3.90

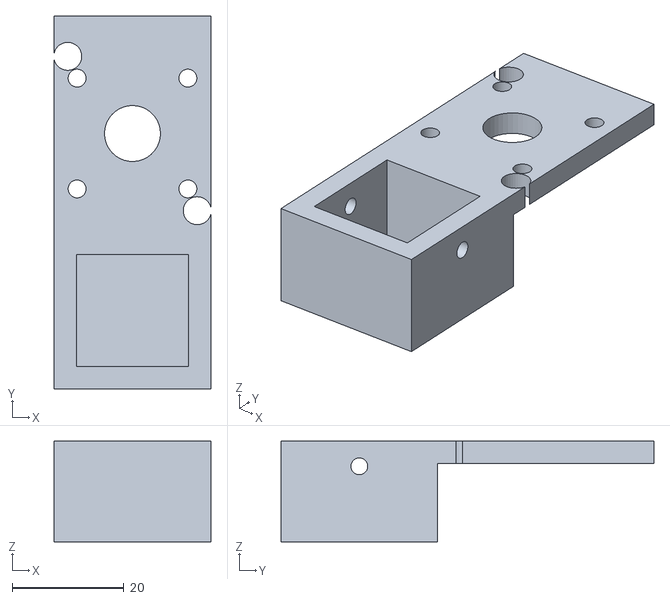
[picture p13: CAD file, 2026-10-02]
models/导轨固定.STL
28.0 x 66.7 x 18.0

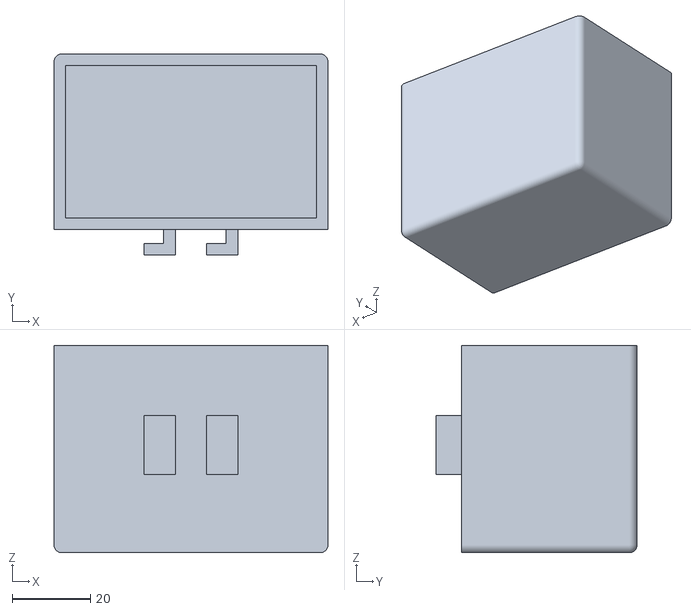
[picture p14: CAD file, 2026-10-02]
models/盒子及钩件.stl
70.0 x 51.4 x 53.0

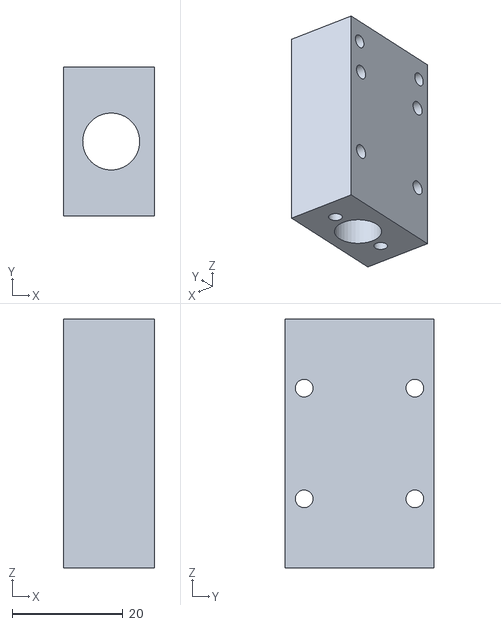
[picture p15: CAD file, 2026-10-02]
models/丝杆导轨连接件.STL
16.5 x 27.0 x 45.0

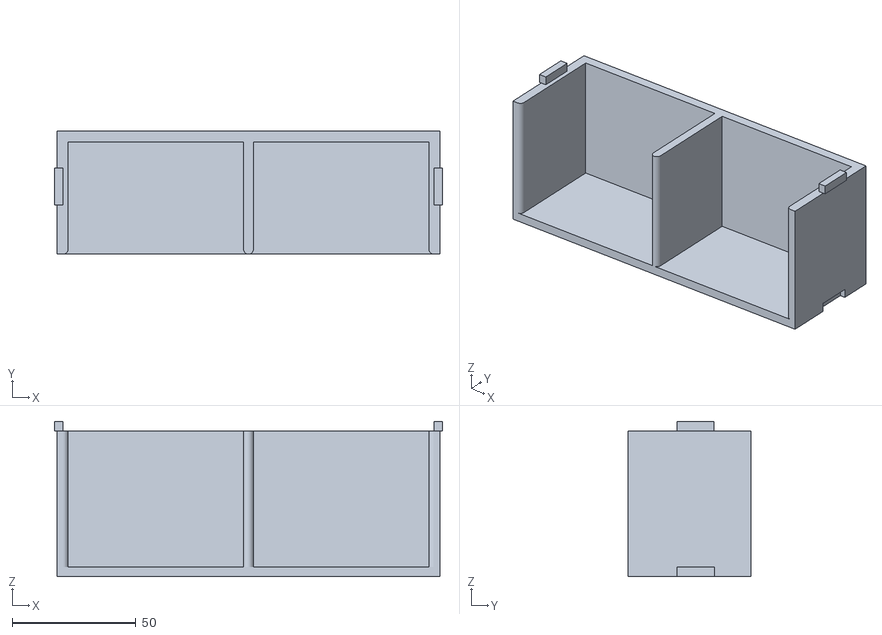
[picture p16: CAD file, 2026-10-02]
models/架子.stl
157.0 x 49.9 x 62.9

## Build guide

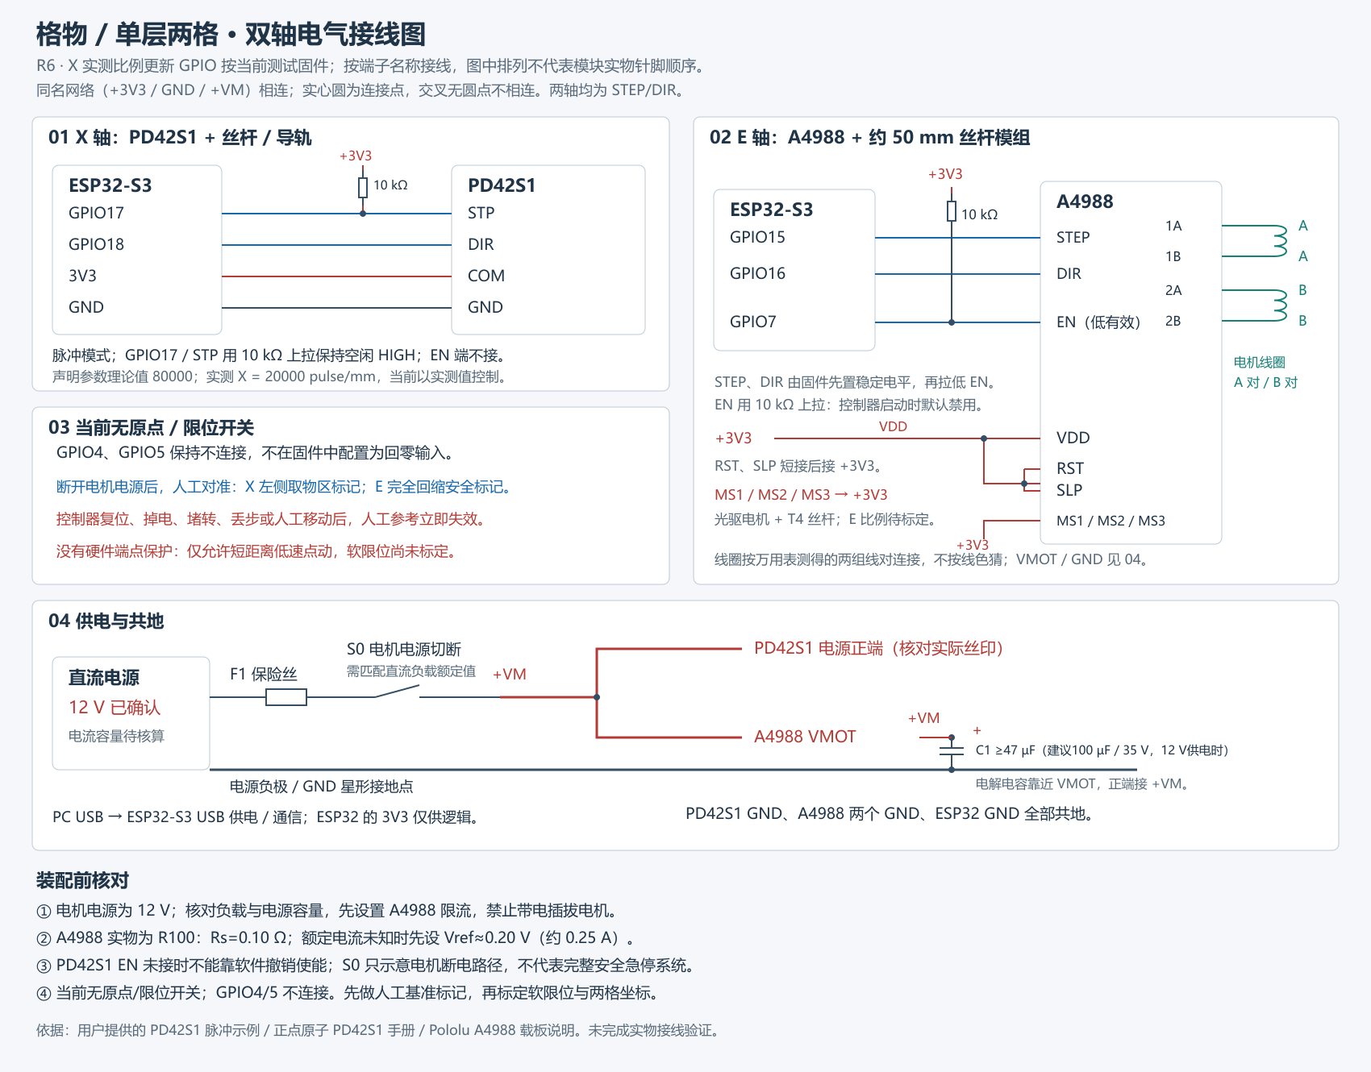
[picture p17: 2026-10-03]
docs/cabinet-wiring.png

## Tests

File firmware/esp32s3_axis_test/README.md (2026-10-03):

# 双轴无开关安全点动固件

这是 ESP32-S3-N16R8 的独立实机测试程序，尚未接入网页取回件流程。当前机构没有 X/E 原点或限位开关，因此固件不支持回零和绝对坐标；上电始终静止，位置始终显示 `UNREFERENCED`。

## 接线和计算

- X：GPIO17 → PD42S1 STP，GPIO18 → DIR。按已有共阳示例，STEP 空闲为高、低脉冲有效；GPIO17/STP 外接 10 kΩ 上拉到 3.3 V。
- E：GPIO15 → A4988 STEP，GPIO16 → DIR，GPIO7 → EN。STEP 高脉冲有效，EN 低有效。
- GPIO4、GPIO5 当前不连接。
- ESP32、PD42S1 信号端和 A4988 必须共地；电机电源与 USB 供电分开。
- X 电机为 1.8°、16 细分，丝杆导程为 2 mm。
- X 轴在 2026-10-03 完成实测：正向与反向均为 `400000 pulse / 20 mm = 20000 pulse/mm`，往返后观察到的回原点误差为 `0 mm`，全程无卡顿或异响。此前根据标称参数算出的 `80000 pulse/mm` 与实测相差 4 倍，暂不再用于运动控制；丝杆实际导程、PD42S1 细分或传动参数仍需单独复核。
- E 为三星光驱拆机微型步进电机，直接驱动标记为 T4 的丝杆。电机步距角、丝杆导程和 `pulse/mm` 均未确认；`T4` 不能直接视为 2 mm 导程。

先核对 PD42S1 面板确实设置为 16 细分。A4988 的 MS1/MS2/MS3 接 3.3 V 才是 16 细分，并按电机额定电流和载板采样电阻设置限流。X EN 未接，停止脉冲后仍可能保持励磁。

## 上电前

电机电源关闭时，将 X 人工移到左侧取物区标记，将 E 人工移到完全回缩且不干涉柜体的位置。确认滑块离两端都有余量。手动移动前必须切断电机电源。

没有开关时，控制器重启、电机掉电、堵转、丢步或人工移动后都会失去参考位置。当前程序不保存坐标，也不把人工位置声明为自动回零。

## 串口测试

打开 USB CDC 串口，115200、换行符 LF。发送：

```text
STATUS
```

应返回 `GEWU-AXIS-TEST-3.0-X-TRAVEL-20MM`、`Xgear=50:1`、`Xscale=20000pulse/mm`、`XpeakSpeed=2.94mm/s`、`Xpositive=RIGHT`、`XlongMax=20mm`、`XEdiag=5pulse/s`、`Escale=UNCALIBRATED`、`Erate=300pulse/s` 和 `EmaxRawPulse=320`。

慢速电平诊断用于确认 GPIO 到驱动器的信号链路：

```text
ARM X CLEAR
TEST X 10

ARM E CLEAR
TEST E 10
```

`TEST X/E 1..50` 以 5 pulse/s 输出，脉冲的有效/空闲电平各保持 100 ms；50 个脉冲持续约 10 秒，便于用万用表测量。X 为低有效，E 为高有效，E 诊断期间自动拉低 GPIO7/A4988 EN。诊断脉冲仍会驱动真实电机，必须先确认机械余量。

每次点动前检查路径和端部余量，然后单独解锁一个轴：

```text
ARM X CLEAR
JOG X 0.5
```

E 轴只能发送原始脉冲：

```text
ARM E CLEAR
PULSE E 320
```

解锁 10 秒后失效，每次解锁只允许一次运动。X `JOG` 单次范围为 0.1–1.0 mm，使用实测 20000 pulse/mm 和对称加减速：从 1 mm/s 起步，在前后各 0.10 mm 内变化到约 2.94 mm/s。X 正数向右。

较长 X 相对位移使用 `TRAVEL X <mm>`，单次允许 ±1–20 mm，与 `JOG X` 使用相同比例和加减速。每次仍须先发送 `ARM X CLEAR`，并人工确认目标方向实际余量大于命令距离。

E 单次范围为 ±16–±320 个原始脉冲，当前排障速率约 300 pulse/s。`JOG E` 会被拒绝，直到实测得到可靠比例。E 正数表示 DIR 高电平，已观察到该方向为回缩。另一台电脑上的诊断已确认 `TEST E 50` 期间 EN 约 0.1 V、STEP 平均约 1.7 V，其他驱动电压正常，但空载电机仍抖动；下一步是断电后将 MS1/MS2/MS3 全部接地，做全步空载测试。尚未确认完成前，不进行 E 位移标定。

此前两次 8000 脉冲测试都跨越了 T4 模组的可用行程、撞到机械端点并丢步，因此不能用其观察距离计算比例。先断开 12 V，把 E 滑块放在行程中部并检查联轴器和丝杆；重新上电后只测试 320 脉冲并测量位移。若一次测试没有接近端点，可从相同方向累计多次，最终按 `累计脉冲数 ÷ 累计位移 mm` 计算 `pulse/mm`。

发送单字符 `!` 可立即请求停止，无需换行；也可发送 `STOP` 加换行。运动中收到其他完整命令也会停止，命令不会排队。运动超时会停止脉冲。关闭串口不会撤销已经开始的有限点动，因此主机必须等待结束回执；软件停止不能检测撞端、卡盒或丢步。

固件故意不提供 `HOME`、连续 `SPIN` 或自动 `FETCH`。先完成 E 原始脉冲标定，再测量 X 取物区、S01、S02、挂钩横移量，以及 E 完全回缩/挂钩深度/完全拉出位置。

## 网页标定助手

烧录本测试固件后，可在项目根目录启动本地标定台：

```powershell
.\start-calibration.ps1 -Port COM9
```

打开 <http://127.0.0.1:3212>。网页仍会严格执行本固件的单次解锁和有限运动约束，并从停止回执读取实际发出的脉冲数。录入卡尺测得的绝对距离后，自动计算轴比例；所有参数完整后才可生成最终控制固件的 `machine_calibration.h`。

## 编译与烧录

在项目根目录运行：

```powershell
& 'C:\Users\XZDD\.platformio\penv\Scripts\pio.exe' run -d firmware/esp32s3_axis_test
& 'C:\Users\XZDD\.platformio\penv\Scripts\pio.exe' run -d firmware/esp32s3_axis_test -t upload --upload-port COMx
```

如果设备重新枚举，使用设备管理器中的新 COM 口。握手失败时，按住 BOOT、短按 RESET/EN、松开 RESET/EN，再松开 BOOT，然后重试烧录。

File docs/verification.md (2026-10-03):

# 2026-10-02 两格两轴更新

- npm test：15/15 通过；npm run check：通过。
- 浏览器：两轴模拟回零、B02 取件、人工位置确认、回件、再次确认；最终 READY、两盒在库。
- 原六格 B03 历史记录仍可查看；不在新布局中可选。
- STL 原始模型四视图已查看，原 STL 未修改；尺寸按 mm 假定。
- 板端协议演练未接入真实运动；无开关点动固件需重新编译、烧录并实测。
- 截图：two-slot-preview.jpg。

## 2026-10-02 无开关硬件修订

- 用户确认 X 带 1:50 减速箱，X/E 均没有微动开关；配置按两轴 1.8°、16 细分、2 mm 导程更新。
- X 计算比例为 80000 pulse/mm，E 为 1600 pulse/mm；尚未做实际位移复核。
- `GEWU-AXIS-TEST-2.0-NO-ENDSTOPS` 已用 PlatformIO / Espressif32 6.3.1 编译通过，RAM 20044 B，固件 291597 B。
- npm test：17/17 通过；npm run check：通过。
- ESP32-S3 重新连接为 COM12（USB VID:PID 303A:1001），`GEWU-AXIS-TEST-2.0-NO-ENDSTOPS` 已烧录且写入校验通过。
- 烧录复位后通过 COM12 / 115200 读取 `STATUS` 成功：`endstops=NONE`、`homing=UNAVAILABLE`、`Xgear=50:1`、`Xscale=80000pulse/mm`、`Escale=1600pulse/mm`、`position=UNREFERENCED`。
- 验证只发送了 `STATUS`，未发送 ARM/JOG，电机未被命令运动。

## 2026-10-02 E 轴 5 mm 点动

- 固件更新为 `GEWU-AXIS-TEST-2.1-NO-ENDSTOPS`：X 单次最大 1 mm，E 单次最大 5 mm。
- COM12 预检通过后发送 `ARM E CLEAR` 和 `JOG E 5.0`。
- 板端返回 `START E pulses=8000 DIR=HIGH`，随后返回 `STOP reason=PULSE_SEQUENCE_DONE_NOT_POSITION_FEEDBACK emitted_pulses=8000`，最终 `moving=-`。
- 以上只证明 8000 个脉冲已发送并自动停机；实际方向、位移、抖动和堵转仍待操作者观察确认。
- 操作者观察：DIR=HIGH 时 E 轴向回缩方向平稳运动，实际距离约 30 mm，而配置距离为 5 mm。
- 由单次粗测得到约 267 pulse/mm，与 1600 pulse/mm 配置不符；在测量 MS1/MS2/MS3 电压和丝杆每圈实际位移前，不修改正式比例。
- 随后发送完全相同的 8000 脉冲、DIR=LOW 反向运动命令，板端正常完成；实际是否回到原位置待操作者确认。
- 实测 MS1、MS2、MS3 均为 0 V，说明 A4988 当时处于全步模式；若丝杆导程为 2 mm，实际比例为 100 pulse/mm，8000 脉冲理论行程为 80 mm。
- 80 mm 超过 E 轴约 50 mm 总行程，因此此前约 30 mm 的观察值不能用于比例标定，机构可能到达机械端点并发生丢步。后续测试前必须把 MS1/MS2/MS3 全部接到 3.3 V，并逐脚复测。
- MS1/MS2/MS3 改接后逐脚实测均为 3.3 V，确认 A4988 已处于 16 细分配置。
- 随后两次 8000 脉冲测试仍从一端移动至另一机械端点并发生丢步，实际位移超过 T4 丝杆模组的可用行程。用户补充 E 电机为三星光驱拆机微型步进电机，因此原先的 1.8°、200 整步/圈和 1600 pulse/mm 假设全部撤销。
- 固件更新为 `GEWU-AXIS-TEST-2.2-E-CALIBRATION`：拒绝 E 轴毫米命令，只允许每次解锁后 ±16–±320 个原始脉冲，速率降为 1000 pulse/s。
- 新固件已编译并烧录至 COM12，写入校验通过。只读 `STATUS` 返回 `armed=-`、`moving=-`、`Escale=UNCALIBRATED`、`EmaxRawPulse=320`；机械检查和人工置中完成前不再发运动命令。
- 置中后 320 脉冲回缩约 5 mm，反向 320 脉冲伸出约 4.5 mm并基本回到中间，两次运动均平稳、无异响或卡顿。粗测分别为约 64 与 71 pulse/mm，尚未作为正式比例。
- 因 1000 pulse/s 的 640 脉冲复测时间太短，不便现场测量，固件标定速率进一步降至 100 pulse/s，版本更新为 `GEWU-AXIS-TEST-2.3-E-SLOW-CALIBRATION`。
- 后续出现板端已发送脉冲但 E 电机间歇性完全无反应；实物检查确认原因是电机线掉焊。此前掉焊期间的位移数据全部视为无效。
- 电机线重新焊接后，`GEWU-AXIS-TEST-2.3-E-SLOW-CALIBRATION` 已重新编译并烧录至 COM12，写入校验通过；只读状态确认 `armed=-`、`moving=-`、`Erate=100pulse/s`、`EmaxRawPulse=320`，尚未执行焊后正式标定。
- 固件随后增加 `TEST X/E 1..50` 慢速诊断：5 pulse/s，每个有效和空闲电平各 100 ms；X 低有效，E 高有效，E 诊断期间自动拉低 GPIO7/A4988 EN。50 个脉冲持续约 10 秒，运动超时调整为 12 秒。
- `TEST E 50` 期间实测 A4988 `EN=0.1 V`、`STEP=1.7 V`；VDD、RESET、SLEEP、MS1/2/3、VREF、VMOT 均报告正常。解除丝杆负载后电机空载依然抖动，因此 GPIO15 STEP、GPIO7 EN 和机械卡滞不再是优先怀疑项。
- E 下一步应在断电状态下将 MS1/MS2/MS3 全部接地，执行全步模式慢速空载测试；若仍只抖动，则更换已知正常的 A4988 交叉测试。该测试尚未确认完成，E 比例仍为未标定。
- X 轴正、反向均以 400000 脉冲实测移动 20 mm，往返后观察到的回原点误差为 0 mm，运动无卡顿或异响；实测比例为 20000 pulse/mm，`DIR=HIGH` 向右。
- X 实测比例与 1.8°、16 细分、1:50 减速和 2 mm 导程推算的 80000 pulse/mm 相差 4 倍。固件以实测比例为准，机械参数差异保留为待核查项。
- X 轴已验证从 20000 pulse/s（1 mm/s）起步，在前后各 2000 脉冲（0.10 mm）内对称加减速至约 58823 pulse/s（2.94 mm/s）；正反向 1 mm 均准确返回，无卡顿、异响或冲击。
- 合并版本 `GEWU-AXIS-TEST-3.0-X-TRAVEL-20MM` 保留 `JOG X` ±0.1–1.0 mm，并新增 `TRAVEL X` ±1–20 mm；仍无原点、反馈和限位，长距离命令必须人工确认机械余量。
- 另一台电脑的非模型更新已合并到当前工作区；当前工作区 STL 按用户说明为更新版本，未被压缩包中的模型覆盖。
- 当前新增/修改模型均通过标准二进制 STL 结构检查：`钩.stl` 700 三角面、包围盒约 27.66 × 77.10 × 32.00；`卡板.stl` 20 三角面、约 70.70 × 6.30 × 55.00；`盒子及钩件1.stl` 1522 三角面、约 70.00 × 44.90 × 53.00（STL 不记录单位）。
- 合并后的 3.0 固件已在本机编译并烧录至 COM12，写入校验通过。只读 `STATUS` 确认 `moving=-`、`Xscale=20000pulse/mm`、`XlongMax=20mm`、`XEdiag=5pulse/s`、`Escale=UNCALIBRATED`，未发送运动命令。

以下为上一版本记录：

# 验证记录

日期：2026-10-02。环境：Windows，Node.js 24.13.0。

- `npm.cmd test`：12 项通过，0 失败。
- `npm.cmd run check`：服务端、业务状态机、设备适配器和前端脚本语法检查通过。
- 浏览器实际操作：模拟回零 → “拿三号盒”解析到 B03 杜邦线 → 确认取件 → 已送达 → 勾选操作区确认 → 回件 → 已归位，完整通过。
- 浏览器歧义验证：“拿螺丝”显示 M3 与 M4 两个候选，不自动执行。
- 当前浏览器 error/warn 日志为空。
- 窄屏布局检查：仍保持上排 S04–S06、下排 S01–S03 的二维位置，预览见 `demo-preview.jpg`。

测试只覆盖软件与模拟设备。未验证：实际麦克风转写、真实串口闭环、驱动器、电机位移比例、人工基准、软限位及机械取放。

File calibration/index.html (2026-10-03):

P

PartGo机械标定台

正在连接—

CALIBRATION CONSOLE · V1

# 把实测位移 变成可靠参数

配合轴测试固件完成有限点动、比例计算与格口坐标录入。每次运动都需要单独确认。

1 / 5

配置完成度

等待读取标定状态

!

当前机构没有限位开关和位置反馈

先把滑块置于行程中间，确认目标方向有足够余量。软件停止不能检测撞端、卡滞或丢步，急停请直接切断电机电源。

立即停止

01

## 控制器连接

刷新状态

工作模式—

串口—

波特率—

02

## 有限运动与比例标定

空闲

X

横向选格轴已知初始比例 20000 pulse/mm

运动距离 ±1–20 mm

mm

我已确认方向与机械余量 执行 X 有限移动

E

前后抽盒轴先用原始脉冲测量实际位移

全步脉冲 ±1–100 pulse

pulse

我已确认方向与机械余量 执行 E 有限移动

录入实测距离

运动结束后，用卡尺测量滑块实际移动距离。

mm

计算 pulse/mm

03

## 机构几何参数

以左侧取物区为 X = 0

E 对接行程

mm

从完全回缩到挂钩对接位置 S01 中心坐标

mm

取物区原点到 1 号格中心 S02 中心坐标

mm

取物区原点到 2 号格中心 X 取盒横移

mm

E 伸出后向右挂住盒子 X DIR 高电平现有测试记录为向右 E DIR 高电平现有测试记录为回缩

暂存几何参数

04

## 标定结果

X 轴比例—

E 轴比例待测量

标定状态

查看固件配置预览

参数完整后生成

写入最终固件配置

写入 machine_calibration.h 后仍需重新编译并烧录最终固件。

05

## 串口记录

LIVE

正在等待日志…

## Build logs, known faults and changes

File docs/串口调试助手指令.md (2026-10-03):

# PartGo 串口调试助手指令（5.2 mm）

## 1. 串口设置

- 串口：`COM9`
- 波特率：`115200`
- 数据位：`8`
- 停止位：`1`
- 校验位：`None`
- 流控：`None`
- 发送格式：文本（不要选 HEX）
- 行尾：`LF`，即 `\n`
- 若软件支持分包发送：每包最多 `64 bytes`，包间隔 `5 ms`

打开串口可能使 ESP32-S3 复位。每次重新打开串口后，都要重新确认机械原点。

> 当前固件没有限位开关和实体急停。发送任何运动指令前，必须确保区域无人无障碍。运动异常时立即发送单字符 `!`，不必等待换行。

## 2. 推荐方式：调用固件自动取还流程

### 2.1 心跳（必须开启）

在串口助手的“定时发送”中添加下面这一行，周期设为 `1000 ms`：

```text
{"v":1,"type":"status","host_session_id":"u"}
```

取出或归还运动期间，如果超过 `2000 ms` 没有收到同一 `host_session_id` 的心跳，控制器会停止并报告 `HOST_HEARTBEAT_TIMEOUT`。

### 2.2 查看状态

```text
STATUS
```

### 2.3 登记机械原点（本指令本身不运动）

仅当 X 位于最左侧取物零点、E 完全回缩、全部盒位已人工核对且区域清空时发送：

```text
{"v":1,"type":"command","task_id":"r1","cmd":"REFERENCE","config_version":6,"calibration_id":"sha256:cc1c95986974daccbf755497cff7d538567dadf5f3a38973d9f94a4cfc739ef8","host_session_id":"u","manual_reference_confirmed":true,"area_clear":true}
```

必须看到：

- `"phase":"REFERENCE_ACCEPTED"`
- `"phase":"HOME_CONFIRMED"`
- `"ok":true`

### 2.4 取出 S01

```text
{"v":1,"type":"command","task_id":"f1","cmd":"FETCH","slot_id":"S01","config_version":6,"calibration_id":"sha256:cc1c95986974daccbf755497cff7d538567dadf5f3a38973d9f94a4cfc739ef8","host_session_id":"u","area_clear":true}
```

必须等到 `task_id` 为 `f1` 的 `"ok":true`，并确认盒子已到左侧取物口，才能发送归还指令。

### 2.5 归还 S01

```text
{"v":1,"type":"command","task_id":"b1","cmd":"RETURN","slot_id":"S01","config_version":6,"calibration_id":"sha256:cc1c95986974daccbf755497cff7d538567dadf5f3a38973d9f94a4cfc739ef8","host_session_id":"u","area_clear":true}
```

### 2.6 取出 S02

```text
{"v":1,"type":"command","task_id":"f2","cmd":"FETCH","slot_id":"S02","config_version":6,"calibration_id":"sha256:cc1c95986974daccbf755497cff7d538567dadf5f3a38973d9f94a4cfc739ef8","host_session_id":"u","area_clear":true}
```

### 2.7 归还 S02

```text
{"v":1,"type":"command","task_id":"b2","cmd":"RETURN","slot_id":"S02","config_version":6,"calibration_id":"sha256:cc1c95986974daccbf755497cff7d538567dadf5f3a38973d9f94a4cfc739ef8","host_session_id":"u","area_clear":true}
```

每个 `task_id` 在同一次控制器会话中只能使用一次。重复测试时改为 `r2`、`f3`、`b3` 等新编号。

## 3. 不支持定时心跳时：短手动指令

每次运动都必须先单独授权，下面两行可以作为一组发送；随后必须等待 `STOP reason=PULSE_SEQUENCE_DONE_NOT_POSITION_FEEDBACK`，才能发送下一组：

```text
ARM X CLEAR
TRAVEL X 5.2
```

```text
ARM E CLEAR
PULSE E 100
```

规则：

- `TRAVEL X`：正数向右，负数向左；单次只能为 `1–20 mm`。
- `PULSE E`：正数伸出，负数回缩；单次只能为 `1–100` 个全步脉冲。
- E 轴对接总量为 `245` 脉冲，必须拆成 `100 + 100 + 45`。
- 勾取向右横移 `5.2 mm`，释放向左横移 `-5.2 mm`。
- 不要把多个运动组一次性粘贴。运动期间收到下一条普通指令，控制器会立即停止当前运动。

### S01 取出（从 X=0、E完全回缩开始）

依次执行并等待每一步 STOP：

1. X：`+20`、`+9.8`
2. E：`+100`、`+100`、`+45`
3. X：`+5.2`
4. E：`-100`、`-100`、`-45`
5. X：`-20`、`-15`

### S01 归还（盒子仍在取物机构上）

1. X：`+20`、`+15`
2. E：`+100`、`+100`、`+45`
3. X：`-5.2`
4. E：`-100`、`-100`、`-45`
5. X：`-20`、`-9.8`

### S02 取出（从 X=0、E完全回缩开始）

1. X：`+20`、`+20`、`+20`、`+20`、`+20`、`+5`
2. E：`+100`、`+100`、`+45`
3. X：`+5.2`
4. E：`-100`、`-100`、`-45`
5. X：`-20`、`-20`、`-20`、`-20`、`-20`、`-10.2`

### S02 归还（盒子仍在取物机构上）

1. X：`+20`、`+20`、`+20`、`+20`、`+20`、`+10.2`
2. E：`+100`、`+100`、`+45`
3. X：`-5.2`
4. E：`-100`、`-100`、`-45`
5. X：`-20`、`-20`、`-20`、`-20`、`-20`、`-5`

如果任何一步出现 `REJECT`、`TIMEOUT`、`HOST_HEARTBEAT_TIMEOUT`、异常声音、卡顿或丢步，不要继续后续位移累加；立即停止、切断 12V，并重新人工建立机械原点。

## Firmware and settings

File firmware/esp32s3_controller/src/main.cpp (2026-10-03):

// PartGo production controller for ESP32-S3-N16R8.
// USB JSONL protocol; no motion on boot; no automatic homing without switches.
#include <Arduino.h>
#include <ctype.h>
#include <math.h>
#include <stdint.h>
#include <stdio.h>
#include <stdlib.h>
#include <string.h>
#include "e_axis.h"
#include "machine_calibration.h"

namespace {

constexpr char FIRMWARE_VERSION[] = "PARTGO-CONTROLLER-2.1.0";
constexpr char PROTOCOL_NAME[] = "partgo-serial-v1";
constexpr int PROTOCOL_VERSION = 1;
constexpr int CONFIG_VERSION = 6;

constexpr int X_STEP_PIN = 17;
constexpr int X_DIR_PIN = 18;
// PD42S1 STEP is wired common-anode: active LOW.
constexpr uint32_t X_ACTIVE_US = 5;
constexpr uint32_t X_START_PERIOD_US = 50;
constexpr uint32_t X_CRUISE_PERIOD_US = 17;
constexpr uint32_t X_RAMP_PULSES = 2000;
// 100 pulses measured 19.6 mm. These rates keep approximately the previous
// 15 mm/s extension and 6.25 mm/s loaded retraction linear speeds.
constexpr uint32_t E_EXTEND_PERIOD_US = 13067;  // ~76.53 pulse/s.
constexpr uint32_t E_RETRACT_PERIOD_US = 31360; // ~31.89 pulse/s.
constexpr uint32_t E_MANUAL_PERIOD_US = 13067;
constexpr uint32_t MOTION_TIMEOUT_MARGIN_MS = 5000;
constexpr uint32_t MOTION_TIMEOUT_MAX_MS = 300000;
constexpr uint32_t MANUAL_ARM_MS = 10000;
constexpr uint32_t HOST_LEASE_MS = 2000;
constexpr uint32_t MANUAL_E_MIN_PULSES = 1;
constexpr uint32_t MANUAL_E_MAX_PULSES = 100;

constexpr partgo::EAxisConfig E_AXIS_CONFIG = {
    15,                         // STEP
    16,                         // DIR
    7,                          // ENABLE, active LOW
    E_DIR_HIGH_EXTENDS,
    E_PULSES_PER_MM,
    E_SCALE_DIVISOR,
    20,                         // STEP high time, microseconds
    MOTION_TIMEOUT_MARGIN_MS,
    MOTION_TIMEOUT_MAX_MS,
};

constexpr int32_t X_MIN_UM = 0;
constexpr int32_t X_MAX_UM = 250000;

constexpr bool HAS_Y_AXIS = false;

struct SlotConfig {
  const char *id;
  bool enabled;
  bool requiresY;
  int32_t xUm;
};

constexpr SlotConfig SLOTS[] = {
    {"S01", true, false, S01_X_UM},
    {"S02", true, false, S02_X_UM},
    {"S03", false, true, -1},
    {"S04", false, true, -1},
};

enum class MachineState { CONFIG_LOCKED, UNREFERENCED, READY, PRESENTED, BUSY, RECOVERY_REQUIRED };
enum class Action { NONE, REFERENCE, RECOVER, FETCH, RETURN_BOX, MANUAL };
enum class Stage : uint8_t {
  NONE,
  FETCH_MOVE_SLOT,
  FETCH_EXTEND,
  FETCH_HOOK_SHIFT,
  FETCH_RETRACT,
  FETCH_MOVE_PICKUP,
  RETURN_MOVE_HOOKED_SLOT,
  RETURN_EXTEND,
  RETURN_UNHOOK_SHIFT,
  RETURN_RETRACT,
  RETURN_MOVE_PICKUP,
};

struct XMotion {
  bool active = false;
  uint32_t remaining = 0;
  uint32_t total = 0;
  uint32_t emitted = 0;
  uint32_t periodUs = 0;
  uint32_t activeUs = 0;
  uint32_t edgeAtUs = 0;
  uint32_t startedAtMs = 0;
  uint32_t timeoutMs = 0;
  bool pulseActive = false;
  int32_t targetUm = 0;
};

MachineState machineState = MachineState::CONFIG_LOCKED;
Action action = Action::NONE;
Stage stage = Stage::NONE;
XMotion xMotion;
partgo::EAxisController eAxis(E_AXIS_CONFIG);
int32_t xPositionUm = 0;
bool referenced = false;
uint32_t eventSequence = 0;
char activeTaskId[65] = "";
char activeHostSessionId[65] = "";
char activeSlotId[5] = "";
char presentedSlotId[5] = "";
char lastTaskId[65] = "";
char inputLine[768];
size_t inputUsed = 0;
bool droppingInput = false;
char manualArmedAxis = 0;
char manualMotionAxis = 0;
uint32_t manualArmedAtMs = 0;
uint32_t lastHostContactMs = 0;

const char *stateName(MachineState value) {
  switch (value) {
    case MachineState::CONFIG_LOCKED: return "CONFIG_LOCKED";
    case MachineState::UNREFERENCED: return "UNREFERENCED";
    case MachineState::READY: return "READY";
    case MachineState::PRESENTED: return "PRESENTED";
    case MachineState::BUSY: return "BUSY";
    case MachineState::RECOVERY_REQUIRED: return "RECOVERY_REQUIRED";
  }
  return "RECOVERY_REQUIRED";
}

bool motionConfigured() {
  if (!CALIBRATION_ID[0] || !X_PULSES_PER_MM || !E_PULSES_PER_MM || !E_SCALE_DIVISOR ||
      E_DOCK_UM <= 0 || E_DOCK_UM > 50000 ||
      X_HOOK_SHIFT_UM <= 0 || X_HOOK_SHIFT_UM > 20000) return false;
  for (const auto &slot : SLOTS) {
    if (!slot.enabled) continue;
    if (slot.requiresY && !HAS_Y_AXIS) return false;
    if (slot.xUm < X_MIN_UM || slot.xUm > X_MAX_UM || slot.xUm + X_HOOK_SHIFT_UM > X_MAX_UM) return false;
  }
  return true;
}

const SlotConfig *findSlot(const char *id) {
  for (const auto &slot : SLOTS) if (!strcmp(slot.id, id)) return &slot;
  return nullptr;
}

bool validId(const char *value) {
  const size_t length = strlen(value);
  if (!length || length > 64) return false;
  for (size_t i = 0; i < length; ++i) {
    const char ch = value[i];
    if (!(isalnum(static_cast<unsigned char>(ch)) || ch == '_' || ch == '-')) return false;
  }
  return true;
}

const char *skipWhitespace(const char *cursor) {
  while (*cursor && isspace(static_cast<unsigned char>(*cursor))) ++cursor;
  return cursor;
}

const char *findJsonValue(const char *json, const char *key) {
  char token[48];
  snprintf(token, sizeof(token), "\"%s\"", key);
  const char *cursor = strstr(json, token);
  if (!cursor) return nullptr;
  cursor = strchr(cursor + strlen(token), ':');
  return cursor ? skipWhitespace(cursor + 1) : nullptr;
}

bool jsonString(const char *json, const char *key, char *out, size_t outSize) {
  const char *cursor = findJsonValue(json, key);
  if (!cursor || *cursor != '"' || outSize < 2) return false;
  ++cursor;
  size_t used = 0;
  while (*cursor && *cursor != '"') {
    if (*cursor == '\\' || static_cast<unsigned char>(*cursor) < 0x20 || used + 1 >= outSize) return false;
    out[used++] = *cursor++;
  }
  if (*cursor != '"') return false;
  out[used] = 0;
  return true;
}

bool jsonBool(const char *json, const char *key, bool &value) {
  const char *cursor = findJsonValue(json, key);
  if (!cursor) return false;
  if (!strncmp(cursor, "true", 4)) { value = true; return true; }
  if (!strncmp(cursor, "false", 5)) { value = false; return true; }
  return false;
}

bool jsonInt(const char *json, const char *key, long &value) {
  const char *cursor = findJsonValue(json, key);
  if (!cursor) return false;
  char *end = nullptr;
  value = strtol(cursor, &end, 10);
  return end != cursor;
}

void sendAck(const char *taskId, bool accepted, const char *error = nullptr) {
  Serial.printf("{\"v\":1,\"type\":\"ack\",\"task_id\":\"%s\",\"accepted\":%s",
                taskId, accepted ? "true" : "false");
  if (error) Serial.printf(",\"error\":\"%s\"", error);
  Serial.println("}");
}

void sendResult(bool success, const char *error = nullptr) {
  if (!activeTaskId[0]) return;
  Serial.printf("{\"v\":1,\"type\":\"result\",\"task_id\":\"%s\",\"success\":%s,\"state\":\"%s\"",
                activeTaskId, success ? "true" : "false", stateName(machineState));
  if (error) Serial.printf(",\"error\":\"%s\"", error);
  Serial.println("}");
}

void sendEvent(const char *phase, const char *sensorFields = nullptr,
               const char *evidence = "open_loop_pulse_count") {
  Serial.printf("{\"v\":1,\"type\":\"event\",\"task_id\":\"%s\",\"seq\":%lu,\"phase\":\"%s\",\"sensors\":{\"evidence\":\"%s\"",
                activeTaskId, static_cast<unsigned long>(++eventSequence), phase,
                evidence);
  if (sensorFields && sensorFields[0]) Serial.printf(",%s", sensorFields);
  Serial.println("}}");
}

void sendStatus(const char *type, const char *requestId) {
  const bool configured = motionConfigured();
  Serial.printf("{\"v\":1,\"type\":\"%s\",\"request_id\":\"%s\",\"protocol\":\"%s\",\"node\":\"ESP32-S3\",\"firmware\":\"%s\",\"state\":\"%s\",\"motion_configured\":%s,\"referenced\":%s,\"busy\":%s,\"config_version\":%d,\"calibration_id\":\"%s\",\"presented_slot_id\":",
                type, requestId, PROTOCOL_NAME, FIRMWARE_VERSION, stateName(machineState),
                configured ? "true" : "false", referenced ? "true" : "false",
                action == Action::NONE ? "false" : "true", CONFIG_VERSION, CALIBRATION_ID);
  if (presentedSlotId[0]) Serial.printf("\"%s\"", presentedSlotId);
  else Serial.print("null");
  Serial.printf(",\"layout\":{\"rows\":2,\"columns\":2,\"has_y_axis\":%s},\"calibration\":{\"x_pulse_per_mm\":%lu,\"e_pulse_per_mm\":%.4f,\"e_scale_numerator\":%lu,\"e_scale_denominator\":%lu,\"e_driver_microsteps\":1,\"e_dock_um\":%ld,\"x_hook_shift_um\":%ld},\"slots\":[",
                HAS_Y_AXIS ? "true" : "false", static_cast<unsigned long>(X_PULSES_PER_MM),
                static_cast<double>(E_PULSES_PER_MM) / E_SCALE_DIVISOR,
                static_cast<unsigned long>(E_PULSES_PER_MM),
                static_cast<unsigned long>(E_SCALE_DIVISOR), static_cast<long>(E_DOCK_UM),
                static_cast<long>(X_HOOK_SHIFT_UM));
  for (size_t i = 0; i < sizeof(SLOTS) / sizeof(SLOTS[0]); ++i) {
    const auto &slot = SLOTS[i];
    if (i) Serial.print(',');
    const bool calibrated = slot.xUm >= X_MIN_UM && slot.xUm <= X_MAX_UM && (!slot.requiresY || HAS_Y_AXIS);
    Serial.printf("{\"id\":\"%s\",\"enabled\":%s,\"calibrated\":%s}", slot.id,
                  slot.enabled ? "true" : "false", calibrated ? "true" : "false");
  }
  Serial.println("]}");
}

void clearTask() {
  action = Action::NONE;
  stage = Stage::NONE;
  activeTaskId[0] = 0;
  activeHostSessionId[0] = 0;
  activeSlotId[0] = 0;
  eventSequence = 0;
}

void setSafeOutputs() {
  digitalWrite(X_STEP_PIN, HIGH);
  eAxis.stopAndDisable();
}

void invalidateReferenceAfterManualMotion() {
  referenced = false;
  xPositionUm = 0;
  eAxis.invalidatePosition();
  machineState = motionConfigured() ? MachineState::UNREFERENCED : MachineState::CONFIG_LOCKED;
}

void stopManualMotion(const char *reason) {
  const uint32_t emitted = manualMotionAxis == 'E' ? eAxis.emittedPulses()
                                                    : xMotion.emitted;
  setSafeOutputs();
  xMotion.active = false;
  manualArmedAxis = 0;
  manualMotionAxis = 0;
  invalidateReferenceAfterManualMotion();
  clearTask();
  Serial.printf("STOP reason=%s emitted_pulses=%lu position=UNREFERENCED\n",
                reason, static_cast<unsigned long>(emitted));
}

void failTask(const char *error) {
  setSafeOutputs();
  xMotion.active = false;
  eAxis.invalidatePosition();
  referenced = false;
  machineState = motionConfigured() ? MachineState::RECOVERY_REQUIRED : MachineState::CONFIG_LOCKED;
  sendResult(false, error);
  strncpy(lastTaskId, activeTaskId, sizeof(lastTaskId) - 1);
  lastTaskId[sizeof(lastTaskId) - 1] = 0;
  clearTask();
}

uint32_t xPulsesFor(int32_t deltaUm) {
  const uint64_t magnitude = static_cast<uint64_t>(deltaUm < 0 ? -static_cast<int64_t>(deltaUm) : deltaUm);
  return static_cast<uint32_t>((magnitude * X_PULSES_PER_MM + 500) / 1000);
}

uint32_t xPeriodForPulse(uint32_t emitted, uint32_t total) {
  uint32_t progress = emitted;
  const uint32_t fromEnd = total > emitted ? total - emitted : 0;
  if (fromEnd < progress) progress = fromEnd;
  if (progress > X_RAMP_PULSES) progress = X_RAMP_PULSES;
  const uint32_t drop = (X_START_PERIOD_US - X_CRUISE_PERIOD_US) * progress / X_RAMP_PULSES;
  return X_START_PERIOD_US - drop;
}

bool startXAbsolute(int32_t targetUm) {
  const int32_t delta = targetUm - xPositionUm;
  const uint32_t pulses = xPulsesFor(delta);
  if (!pulses) {
    xPositionUm = targetUm;
    return false;
  }
  xMotion = {};
  xMotion.active = true;
  xMotion.remaining = pulses;
  xMotion.total = pulses;
  xMotion.targetUm = targetUm;
  xMotion.activeUs = X_ACTIVE_US;
  xMotion.periodUs = X_START_PERIOD_US;
  xMotion.edgeAtUs = micros();
  xMotion.startedAtMs = millis();
  const uint32_t nominalPeriod = X_CRUISE_PERIOD_US;
  const uint64_t estimatedMs = static_cast<uint64_t>(pulses) * nominalPeriod / 1000 + MOTION_TIMEOUT_MARGIN_MS;
  xMotion.timeoutMs = static_cast<uint32_t>(estimatedMs > MOTION_TIMEOUT_MAX_MS ? MOTION_TIMEOUT_MAX_MS : estimatedMs);
  const bool directionHigh = (delta > 0) == X_DIR_HIGH_MOVES_RIGHT;
  digitalWrite(X_DIR_PIN, directionHigh ? HIGH : LOW);
  digitalWrite(X_STEP_PIN, HIGH);
  return true;
}

bool startEAbsolute(int32_t targetUm, uint32_t periodUs,
                    bool holdAfterCompletion) {
  const auto result = eAxis.startAbsolute(targetUm, periodUs,
                                          holdAfterCompletion);
  if (result == partgo::EAxisStartResult::STARTED) return true;
  if (result == partgo::EAxisStartResult::ALREADY_AT_TARGET) return false;
  failTask(result == partgo::EAxisStartResult::POSITION_UNKNOWN
               ? "E_POSITION_UNKNOWN"
               : "E_AXIS_START_FAILED");
  return true;
}

void sendManualStatus() {
  Serial.printf(
      "%s mode=FINAL_MANUAL armed=%c moving=%c endstops=NONE homing=MANUAL "
      "Xscale=%lupulse/mm XdirHigh=%s XlongMax=20mm "
      "Escale=%lu/%lupulse/mm Emicrostep=FULL EdirHigh=%s "
      "Econtroller=DEDICATED_V2 Eextend=76.53pulse/s Eretract=31.89pulse/s EmaxRawPulse=100 "
      "state=%s position=%s NO_ENDSTOP_PROTECTION\n",
      FIRMWARE_VERSION, manualArmedAxis ? manualArmedAxis : '-',
      action == Action::MANUAL && xMotion.active ? 'X'
          : action == Action::MANUAL && eAxis.busy() ? 'E' : '-',
      static_cast<unsigned long>(X_PULSES_PER_MM),
      X_DIR_HIGH_MOVES_RIGHT ? "RIGHT" : "LEFT",
      static_cast<unsigned long>(E_PULSES_PER_MM),
      static_cast<unsigned long>(E_SCALE_DIVISOR),
      E_DIR_HIGH_EXTENDS ? "EXTEND" : "RETRACT", stateName(machineState),
      referenced ? "REFERENCED" : "UNREFERENCED");
}

bool manualAvailable() {
  if (action != Action::NONE || xMotion.active || eAxis.busy()) {
    Serial.println("REJECT BUSY");
    return false;
  }
  if (machineState == MachineState::PRESENTED || presentedSlotId[0]) {
    Serial.println("REJECT BOX_PRESENTED_MANUAL_DISABLED");
    return false;
  }
  return true;
}

bool consumeManualArm(char axis) {
  const bool permitted = manualArmedAxis == axis &&
                         uint32_t(millis() - manualArmedAtMs) < MANUAL_ARM_MS;
  manualArmedAxis = 0;
  if (!permitted) Serial.println("REJECT ARM_REQUIRED");
  return permitted;
}

void startManualX(float mm) {
  invalidateReferenceAfterManualMotion();
  action = Action::MANUAL;
  manualMotionAxis = 'X';
  const int32_t deltaUm = static_cast<int32_t>(lroundf(mm * 1000.0f));
  if (!startXAbsolute(deltaUm)) {
    stopManualMotion("ZERO_DISTANCE");
    return;
  }
  Serial.printf(
      "START TRAVEL X distance=%.3fmm pulses=%lu DIR=%s "
      "NO_ENDSTOP_PROTECTION\n",
      mm, static_cast<unsigned long>(xMotion.total),
      digitalRead(X_DIR_PIN) == HIGH ? "HIGH" : "LOW");
}

void startManualE(long signedPulses) {
  invalidateReferenceAfterManualMotion();
  action = Action::MANUAL;
  manualMotionAxis = 'E';
  const auto result = eAxis.startRawSigned(static_cast<int32_t>(signedPulses),
                                           E_MANUAL_PERIOD_US);
  if (result != partgo::EAxisStartResult::STARTED) {
    stopManualMotion("E_AXIS_START_FAILED");
    return;
  }
  Serial.printf("START E raw_pulses=%lu DIR=%s SCALE=%lu/%lupulse/mm MICROSTEP=FULL NO_ENDSTOP_PROTECTION\n",
                static_cast<unsigned long>(eAxis.commandedPulses()),
                eAxis.directionPinHigh() ? "HIGH" : "LOW",
                static_cast<unsigned long>(E_PULSES_PER_MM),
                static_cast<unsigned long>(E_SCALE_DIVISOR));
}

void handleManualCommand(char *input) {
  if (!strcmp(input, "STATUS")) {
    sendManualStatus();
    return;
  }
  if (!strcmp(input, "STOP")) {
    if (action == Action::MANUAL) stopManualMotion("COMMAND");
    else if (action != Action::NONE) failTask("STOP_REQUESTED");
    else {
      setSafeOutputs();
      manualArmedAxis = 0;
      referenced = false;
      machineState = motionConfigured() ? MachineState::UNREFERENCED
                                        : MachineState::CONFIG_LOCKED;
      Serial.println("STOP reason=COMMAND emitted_pulses=0 position=UNREFERENCED");
    }
    return;
  }
  if (action == Action::MANUAL || xMotion.active || eAxis.busy()) {
    stopManualMotion("COMMAND_DURING_MOTION");
    return;
  }
  if (!strcmp(input, "ARM X CLEAR") || !strcmp(input, "ARM E CLEAR")) {
    if (!manualAvailable()) return;
    manualArmedAxis = input[4];
    manualArmedAtMs = millis();
    Serial.printf("ARMED %c one_motion_only expires=10s NO_ENDSTOP_PROTECTION\n",
                  manualArmedAxis);
    return;
  }

  char axis = 0, extra = 0;
  float mm = 0;
  if (sscanf(input, "TRAVEL %c %f %c", &axis, &mm, &extra) == 2 && axis == 'X') {
    if (!consumeManualArm('X')) return;
    if (!isfinite(mm) || fabsf(mm) < 1.0f || fabsf(mm) > 20.0f) {
      Serial.println("REJECT X_TRAVEL_RANGE_1_TO_20_MM");
      return;
    }
    if (!manualAvailable()) return;
    startManualX(mm);
    return;
  }

  long signedPulses = 0;
  if (sscanf(input, "PULSE %c %ld %c", &axis, &signedPulses, &extra) == 2 && axis == 'E') {
    if (!consumeManualArm('E')) return;
    if ((signedPulses > -static_cast<long>(MANUAL_E_MIN_PULSES) &&
         signedPulses < static_cast<long>(MANUAL_E_MIN_PULSES)) ||
        signedPulses < -static_cast<long>(MANUAL_E_MAX_PULSES) ||
        signedPulses > static_cast<long>(MANUAL_E_MAX_PULSES)) {
      Serial.println("REJECT E_RAW_RANGE_1_TO_100_FULL_STEPS");
      return;
    }
    if (!manualAvailable()) return;
    startManualE(signedPulses);
    return;
  }

  manualArmedAxis = 0;
  Serial.println("REJECT UNKNOWN_COMMAND");
}

void finishSuccess() {
  if (action == Action::FETCH) {
    strncpy(presentedSlotId, activeSlotId, sizeof(presentedSlotId) - 1);
    presentedSlotId[sizeof(presentedSlotId) - 1] = 0;
    machineState = MachineState::PRESENTED;
  } else {
    if (action == Action::RETURN_BOX) presentedSlotId[0] = 0;
    machineState = MachineState::READY;
  }
  sendResult(true);
  strncpy(lastTaskId, activeTaskId, sizeof(lastTaskId) - 1);
  lastTaskId[sizeof(lastTaskId) - 1] = 0;
  clearTask();
}
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
void loop() {
  tickMotion();
  if (manualArmedAxis && uint32_t(millis() - manualArmedAtMs) >= MANUAL_ARM_MS) {
    manualArmedAxis = 0;
    Serial.println("DISARMED EXPIRED");
  }
  int budget = 48;
  while (Serial.available() && budget-- > 0) {
    const char ch = static_cast<char>(Serial.read());
    if (ch == '!') {
      if (action == Action::MANUAL) stopManualMotion("IMMEDIATE_STOP");
      else if (action != Action::NONE) failTask("IMMEDIATE_STOP");
      else {
        setSafeOutputs();
        referenced = false;
        machineState = motionConfigured() ? MachineState::UNREFERENCED
                                          : MachineState::CONFIG_LOCKED;
      }
      manualArmedAxis = 0;
      inputUsed = 0;
      droppingInput = true;
    } else if (ch == '\n') {
      if (!droppingInput && inputUsed) {
        inputLine[inputUsed] = 0;
        const char *first = skipWhitespace(inputLine);
        if (*first == '{') handleCommand(first);
        else handleManualCommand(inputLine);
      }
      inputUsed = 0;
      droppingInput = false;
    } else if (ch != '\r' && !droppingInput) {
      if (inputUsed >= sizeof(inputLine) - 1) {
        if (action != Action::NONE) failTask("INPUT_OVERFLOW");
        inputUsed = 0;
        droppingInput = true;
      } else {
        inputLine[inputUsed++] = ch;
      }
    }
    tickMotion();
  }
}

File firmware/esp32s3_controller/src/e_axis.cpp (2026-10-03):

#include "e_axis.h"

#include <Arduino.h>

namespace partgo {

EAxisController::EAxisController(const EAxisConfig &config) : config_(config) {}

void EAxisController::begin() {
  // Write safe levels before changing pin direction to prevent an enable or
  // STEP glitch during boot.
  digitalWrite(config_.enablePin, HIGH);
  pinMode(config_.enablePin, OUTPUT);
  digitalWrite(config_.stepPin, LOW);
  pinMode(config_.stepPin, OUTPUT);
  digitalWrite(config_.directionPin, LOW);
  pinMode(config_.directionPin, OUTPUT);
  active_ = false;
  pulseHigh_ = false;
  positionKnown_ = false;
}

void EAxisController::referenceRetracted() {
  if (active_) return;
  positionUm_ = 0;
  targetUm_ = 0;
  positionKnown_ = true;
}

void EAxisController::invalidatePosition() {
  positionKnown_ = false;
}

void EAxisController::disableDriver() {
  digitalWrite(config_.stepPin, LOW);
  digitalWrite(config_.enablePin, HIGH);
}

void EAxisController::stopAndDisable() {
  disableDriver();
  active_ = false;
  pulseHigh_ = false;
  positionKnown_ = false;
}

uint32_t EAxisController::pulsesForDistanceUm(int32_t distanceUm) const {
  const uint64_t magnitude = static_cast<uint64_t>(
      distanceUm < 0 ? -static_cast<int64_t>(distanceUm) : distanceUm);
  const uint64_t denominator = 1000ULL * config_.scaleDivisor;
  if (!denominator) return 0;
  return static_cast<uint32_t>(
      (magnitude * config_.scaleNumerator + denominator / 2) / denominator);
}

EAxisStartResult EAxisController::startLogical(
    bool extends, uint32_t pulses, uint32_t periodUs,
    bool holdAfterCompletion, bool absoluteMove, int32_t targetUm) {
  if (active_) return EAxisStartResult::BUSY;
  if (!pulses || periodUs <= config_.activePulseUs) {
    return EAxisStartResult::INVALID_COMMAND;
  }

  directionPinHigh_ = extends == config_.directionHighExtends;
  digitalWrite(config_.directionPin, directionPinHigh_ ? HIGH : LOW);
  digitalWrite(config_.stepPin, LOW);
  digitalWrite(config_.enablePin, LOW);

  active_ = true;
  pulseHigh_ = false;
  holdAfterCompletion_ = holdAfterCompletion;
  absoluteMove_ = absoluteMove;
  targetUm_ = targetUm;
  remainingPulses_ = pulses;
  totalPulses_ = pulses;
  emittedPulses_ = 0;
  periodUs_ = periodUs;
  edgeAtUs_ = micros();
  startedAtMs_ = millis();
  const uint64_t estimatedMs =
      static_cast<uint64_t>(pulses) * periodUs / 1000 + config_.timeoutMarginMs;
  timeoutMs_ = static_cast<uint32_t>(
      estimatedMs > config_.timeoutMaximumMs ? config_.timeoutMaximumMs
                                             : estimatedMs);
  return EAxisStartResult::STARTED;
}

EAxisStartResult EAxisController::startAbsolute(
    int32_t targetUm, uint32_t periodUs, bool holdAfterCompletion) {
  if (active_) return EAxisStartResult::BUSY;
  if (!positionKnown_) return EAxisStartResult::POSITION_UNKNOWN;
  const int32_t deltaUm = targetUm - positionUm_;
  if (!deltaUm) return EAxisStartResult::ALREADY_AT_TARGET;
  const uint32_t pulses = pulsesForDistanceUm(deltaUm);
  return startLogical(deltaUm > 0, pulses, periodUs, holdAfterCompletion,
                      true, targetUm);
}

EAxisStartResult EAxisController::startRawSigned(int32_t signedPulses,
                                                  uint32_t periodUs) {
  if (active_) return EAxisStartResult::BUSY;
  if (!signedPulses) return EAxisStartResult::INVALID_COMMAND;
  const uint32_t pulses = static_cast<uint32_t>(
      signedPulses < 0 ? -static_cast<int64_t>(signedPulses) : signedPulses);
  const auto result =
      startLogical(signedPulses > 0, pulses, periodUs, false, false, 0);
  if (result == EAxisStartResult::STARTED) positionKnown_ = false;
  return result;
}

EAxisTickResult EAxisController::tick() {
  if (!active_) return EAxisTickResult::IDLE;
  if (static_cast<uint32_t>(millis() - startedAtMs_) > timeoutMs_) {
    stopAndDisable();
    return EAxisTickResult::TIMED_OUT;
  }

  const uint32_t nowUs = micros();
  if (pulseHigh_) {
    if (static_cast<uint32_t>(nowUs - edgeAtUs_) < config_.activePulseUs) {
      return EAxisTickResult::RUNNING;
    }
    digitalWrite(config_.stepPin, LOW);
    pulseHigh_ = false;
    edgeAtUs_ = nowUs;
    if (!remainingPulses_) {
      active_ = false;
      if (absoluteMove_) {
        positionUm_ = targetUm_;
        positionKnown_ = true;
      }
      if (!holdAfterCompletion_) disableDriver();
      return EAxisTickResult::COMPLETED;
    }
    return EAxisTickResult::RUNNING;
  }

  if (static_cast<uint32_t>(nowUs - edgeAtUs_) <
      periodUs_ - config_.activePulseUs) {
    return EAxisTickResult::RUNNING;
  }
  digitalWrite(config_.stepPin, HIGH);
  pulseHigh_ = true;
  edgeAtUs_ = nowUs;
  --remainingPulses_;
  ++emittedPulses_;
  return EAxisTickResult::RUNNING;
}

}  // namespace partgo

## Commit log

2026-10-02 Update wiring diagram for no-endstop hardware
2026-10-02 Record ESP32-S3 firmware verification
2026-10-02 Record A4988 R100 current-limit settings
2026-10-02 Allow and verify five millimeter E-axis jog
2026-10-02 Record A4988 full-step wiring fault
2026-10-02 make E-axis calibration pulse-safe
2026-10-02 Update E-axis calibration and mechanical models
    [E轴电机槽.stl, 减速电机固定.STL, 导轨固定.STL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]
2026-10-02 record repaired E-axis motor wiring
2026-10-03 add guarded motion calibration console
2026-10-03 reset calibration form after service restart
2026-10-03 record E axis calibration at 21 pulse per mm
2026-10-03 finalize two-slot motion calibration
2026-10-03 switch E axis driver to full step
2026-10-03 correct E axis full-step travel scale
    [calibration_server.py, main.cpp]
2026-10-03 update final axis calibration and slot coordinates
2026-10-03 calibrate E axis and add local launchers
2026-10-03 fix pyserial interpreter selection
    [calibration_server.py]
2026-10-03 harden hardware workflow and finalize motion calibration
